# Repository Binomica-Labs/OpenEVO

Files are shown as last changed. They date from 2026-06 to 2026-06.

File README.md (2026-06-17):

# OpenEvo — Open Evolution Turbidostat

**Authors:** Zane Chan, Pin-Che Huang, Phillip Kyriakakis  
**License:** [MIT](https://opensource.org/licenses/MIT)  
**Latest Release:** [V1.1 — June 17, 2026](OpenEvo_2026-06-17_Release_V1.1.zip)

---

OpenEvo is an open-source turbidostat for continuous-culture directed evolution. It runs as a browser-based interface on any computer connected to an Arduino Mega 2560, with real-time OD monitoring, automated media changes, and optional one-click global remote access via Cloudflare Tunnel — no cloud account or router configuration needed.

---

## Download & Run

**The easiest way to get started is to download the release zip — it contains everything you need:**

➡️ [`OpenEvo_2026-06-17_Release_V1.1.zip`](OpenEvo_2026-06-17_Release_V1.1.zip) (~60 MB — includes Python interface, Arduino firmware, software interface manual, launchers, installers, and Cloudflare tunnel binaries for remote access)

**Full archive including hardware assembly manual** also available on Zenodo:  
➡️ [https://doi.org/10.5281/zenodo.20694532](https://doi.org/10.5281/zenodo.20694532)

Inside the zip you will find a `README.txt` with full installation instructions. The short version:

1. Extract the zip to a permanent location
2. Run `Windows_Install_OpenEvo.bat` or `Mac_Install_OpenEvo.command` to install Python packages
3. Upload `2026-06-04_OpenEvo_Firmware_V1.ino` to your Arduino Mega 2560 via Arduino IDE
4. Run `Windows_Run_OpenEvo.bat` or `Mac_Run_OpenEvo.command`
5. Open **http://localhost:8080** in your browser and click **Connect**

---

## What's in This Repository

| File | Description |
|---|---|
| `2026-06-17_OpenEvo_Interface_V1.1.py` | Main Python web interface (latest) |
| `2026-06-04_OpenEvo_Firmware_V1.ino` | Arduino Mega 2560 firmware |
| `OpenEVO Interface Manual.pdf` | Software interface manual |
| `Windows_Run_OpenEvo.bat` | Windows launcher |
| `Mac_Run_OpenEvo.command` | Mac launcher |
| `Windows_Install_OpenEvo.bat` | Windows package installer |
| `Mac_Install_OpenEvo.command` | Mac package installer |
| `requirements.txt` | Python dependencies |
| `OpenEvo_TEST_CHECKLIST.html` | Interactive release test checklist |
| `OpenEvo_2026-06-17_Release_V1.1.zip` | Full release zip (tracked via Git LFS) |

---

## Features

- Real-time OD monitoring with live plotting
- Automated media dilution at a configurable OD threshold
- LED cycling for directed evolution experiments
- 2–4 point OD calibration using an inverse least-squares model (`OD = a/IR + b`)
- SD card persistence — config and data survive power cycles
- Manual pump control and a cycle program editor
- CSV data export with UTC timestamps
- **One-click global remote access** via Cloudflare Tunnel (bundled, no account required)
  - Generates a public URL instantly
  - All viewers — local and remote — see the same live interface

---

## Hardware

- Arduino Mega 2560
- IR optical density sensor
- NTC thermistor temperature sensors
- Peristaltic pumps
- Stirrer motor
- LEDs
- SD card module
- USB data cable

---

## Software Requirements

- Python 3.10 or newer
- NiceGUI 3.4.1 (`pip install nicegui==3.4.1`)
- PySerial (`pip install pyserial`)
- Arduino IDE 2.x
- Windows 10/11, macOS 10.15+, or Linux

---

## Release History

| Release | Date | Notes |
|---|---|---|
| V1 | 2026-06-11 | Current release |

---

## License

MIT — see [https://opensource.org/licenses/MIT](https://opensource.org/licenses/MIT)

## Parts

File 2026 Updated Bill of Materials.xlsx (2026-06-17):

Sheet: 2025-11-24
Part Name | Quantity Needed | Retail Quantity | Unit price | Price for all | Vendor | URL
IC I2C TB6612 Mosfet Stepper Motor PCA9685 Servo Driver Shield V2 For Robot PWM Mega R3 | 1 | 1 | $9.98 | $9.98 | AliExpress | https://www.aliexpress.us/item/3256808443179819.html?curPageLogUid=ypC1EHNQtV5V
Adafruit DS3231 Real-Time Clock | 1 | 1 | $10.01 | $10.01 | AliExpress | https://www.aliexpress.us/item/3256810164925988.html?curPageLogUid=7wuj5i6TvdWM
TLC5947 module 12-Bit 24-Channel PWM LED Driver Module With Internal Oscillator 12 Bit 3-5.5V | 1 | 1 | $14.00 | $14.00 | Alibaba | https://www.alibaba.com/product-detail/TLC5947-module-12-Bit-24-Channel_62586041214.html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
Adafruit DRV8871 DC Motor Controller | 1 | 5 | $2.60 | $2.60 | AliExpress | https://www.aliexpress.us/item/3256809806051721.html?curPageLogUid=Eqp3fZFoM7K1
TSL2591 Light Sensor | 1 | 2 | $2.80 | $2.80 | Alibaba | https://www.alibaba.com/product-detail/TSL2591-Digital-Light-Sensor-Breakout-Module_1601221697469.html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
TCA9548A I2C Multiplexer Module – 1-to-8 Channel Expansion Board for IIC Bus (8-Way | 1 | 1 | $1.58 | $1.58 | AliExpress | https://www.adafruit.com/product/2717
DC Motor Peristaltic Pump | 4 | 1 | $3.66 | $14.64 | AliExpress | https://www.aliexpress.us/item/3256805882232786.html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
PTC Heating Plate 80C | 1 | 1 | $1.08 | $1.08 | AliExpress | https://www.aliexpress.us/item/2255799902168723.html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
Waterproof Button | 3 | 10 | $4.68 | $4.68 | AliExpress | https://www.aliexpress.us/item/3256803116546507.html?curPageLogUid=xL4qqrG5PEyM
5mm x 300mm Steel Rod | 2 | 2 | $1.09 | $1.09 | AliExpress | https://www.aliexpress.us/item/3256809453294379.html?curPageLogUid=2q5RW11g6f6b
Serial IIC I2C TWI 2004 204 20*4 English & Japanese Character LCD Module Display Panel Screen for Arduino | 1 | 1 | $3.52 | $3.52 | AliExpress | https://www.amazon.com/gp/product/B07TXGD3WS/ref=ppx_yo_dt_b_search_asin_title?ie=UTF8&psc=1
Matte Black PLA Filament | 1 | 1 | $17.40 | $17.40 | AliExpress | https://www.aliexpress.us/item/3256808648181661.html?curPageLogUid=riVaaNLBrUrJ
Arduino MEGA 2560 R3 | 1 | 1 | $15.58 | $15.58 | AliExpress | https://www.aliexpress.us/item/3256808853354044.html?curPageLogUid=15EhXzMV496T
12v to 5v Converter | 1 | 1 | $4.65 | $4.65 | AliExpress | https://www.aliexpress.us/item/3256806995523749.html?curPageLogUid=ehhkYzvOyuks
Pin Connector | 50 | 100 | $1.35 | $1.35 | AliExpress | https://www.aliexpress.us/item/3256806077264771.html?spm=a2
Pin Connector Housing | 100 | 100 | $1.67 | $1.67 | AliExpress | https://www.aliexpress.us/item/3256809102805756.html?curPageLogUid=IOLAuUAzc9Qd
M2.5 x 10mm Female Standoff | 20 | 20 | $3.25 | $3.25 | AliExpress | https://www.aliexpress.us/item/3256805863280885.html?curPageLogUid=uJjQn4AfzCel
M3 x 10mm Female Standoff | 20 | 20 | $2.81 | $2.81 | AliExpress | https://www.aliexpress.us/item/3256805863280885.html?curPageLogUid=uJjQn4AfzCel
Dispensing Needle 14ga 4" | 2 | 20 | $5.00 | $5.00 | AliExpress | https://www.aliexpress.us/item/3256806422675515.html
10 Pack - Dispensing Needle 10G x 5" - Blunt Tip, Luer Lock, All Metal (Stainless Steel) | 1 | 1 | $3.83 | $3.83 | AliExpress | https://www.aliexpress.us/item/2255800730053112.html?curPageLogUid=V4wyD2ZV2IoS
Dispensing Needle 14ga 1.5" | 4 | 12 | $3.74 | $3.74 | AliExpress | https://www.aliexpress.us/item/3256808088472590.html?curPageLogUid=Nd4i0lxbjFsQ
8mm x 20mm olive-shaped stir bar | 1 | 1 | $1.15 | $1.15 | AliExpress | https://www.aliexpress.us/item/2255801153708621.html?curPageLogUid=j1jyPPY7cOp3
90mL Glass Vial | 1 | 6 | $16.99 | $16.99 | AliExpress | https://www.aliexpress.us/item/3256803514646833.html?srcSns=sns_Copy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
Barrel Jack Connector 5.5x2.1mm | 1 | 1 | $2.41 | $2.41 | AliExpress | https://www.aliexpress.us/item/3256803320286941.html?curPageLogUid=eMrwFr4nFsgy
Industrial MicroSD Card 32Gb | 1 | 1 | $5.64 | $5.64 | AliExpress | https://www.aliexpress.us/item/3256807576760784.html?curPageLogUid=tyVm4Ekr2Y1j
M2.5 Hex Screw Kit 4mm, 10mm | 1 | 50 each | $3.93 | $3.93 | AliExpress | https://www.aliexpress.us/item/3256803907721123.html?curPageLogUid=memrVmdLUUmt
M3 Hex Screw Kit 4mm, 10mm, 20mm | 1 | 50 each | $7.06 | $7.06 | AliExpress | https://www.aliexpress.us/item/2251832793785357.html?curPageLogUid=0Fh3A0FxOjEa
Double Sided Tape Heavy Duty | 1 | 1 | $2.43 | $2.43 | AliExpress | https://www.aliexpress.us/item/3256804426987395.html?curPageLogUid=xIfYy00LLE2k
Rocker Switch | 1 | 5 | $1.43 | $1.43 | AliExpress | https://www.aliexpress.us/item/2251832687071918.html?curPageLogUid=4V8XkcMblquU
CR1220 Lithium Battery | 1 | 5 | $3.18 | $3.18 | AliExpress | https://www.aliexpress.us/item/3256808697007607.html?curPageLogUid=drx6CjwDRf4p
Silicone Tubing 1/8" ID x 1/4" OD | 5m | 5m | $6.02 | $6.02 | AliExpress | https://www.aliexpress.us/item/3256807463903641.html?curPageLogUid=STi7P96EXRlY
L298N Motor Controller | 1 | 1 | $2.04 | $2.04 | AliExpress | https://www.aliexpress.us/item/3256805515428257.html?curPageLogUid=RA7wxDvjNB5x
Female Pin Header Kit | 1 | 10 | $6.36 | $6.36 | AliExpress | https://www.aliexpress.us/item/3256803424019097.html?curPageLogUid=tNNR6Pz63qkk
Male Pin Header Strips | 2 | 10 | $3.93 | $3.93 | AliExpress | https://www.aliexpress.us/item/3256809164675006.html?curPageLogUid=NwdbH9P0lvf9
Male Pin Header Right Angle Strips | 1 | 10 | $1.54 | $1.54 | AliExpress | https://www.aliexpress.us/item/3256807383526945.html?curPageLogUid=kdMGiPZ6hEm8
2.54mm Jumper Caps | 4 | 100 | $1.26 | $1.26 | AliExpress | https://www.aliexpress.us/item/3256805359306528.html?curPageLogUid=xutyn0z4C155
12v 5A Power Supply | 1 | 1 | $8.05 | $8.05 | AliExpress | https://www.aliexpress.us/item/3256805577151044.html?curPageLogUid=hN4PaRkEcDTU
Square Adhesive Rubber Feet | 1 | 40 | $2.92 | $2.92 | AliExpress | https://www.aliexpress.us/item/2251832785210189.html?curPageLogUid=zY0jLTF8NWrz
PES 0.22um Syringe Filters | 5 | 10 | $11.15 | $11.15 | AliExpress | https://www.aliexpress.us/item/3256806983863516.html?curPageLogUid=6LAvoEP7xlQJ
Neodymium Magnets 12x6x3mm | 16 | 20 | $4.20 | $4.20 | AliExpress | https://www.aliexpress.us/item/3256809286779220.html?curPageLogUid=kWDl0wbewySA
PC Fan 40x20mm | 1 | 1 | $2.86 | $2.86 | AliExpress | https://www.aliexpress.us/item/3256802954170154.html?curPageLogUid=QPYlJY3zycg1
MicroSD Card Module | 1 | 1 | $1.00 | $1.00 | AliExpress | https://www.aliexpress.us/item/3256806271288304.html?curPageLogUid=6h4WNfpqXEIP
Black High Temp Silicone Sealant | 1 | 1 | $3.44 | $3.44 | AliExpress | https://www.aliexpress.us/item/3256809082794580.html?curPageLogUid=5iZxJbS0rAOQ
22AWG Silicone Wire Kit Box 1 | 1 | 1 | $17.16 | $17.16 | AliExpress | https://www.aliexpress.us/item/3256806872487663.html?curPageLogUid=m3JkRzS8uJco
22AWG Silicone Wire Kit Box 2 | 1 | 1 | $16.86 | $16.86 | AliExpress | https://www.aliexpress.us/item/3256806872487663.html?curPageLogUid=m3JkRzS8uJco
Smooth Flow Flux | 1 | 1 | $5.54 | $5.54 | AliExpress | https://www.aliexpress.us/item/3256807619367300.html?curPageLogUid=2C5Q7TgWCZ7L
Lead-Free Solder | 1 | 1 | $4.59 | $4.59 | AliExpress | https://www.aliexpress.us/item/3256807913795917.html?curPageLogUid=2KA0dfwCmOtA
Hard Silicone Rubber Casting Resin | 1 | 1 | $20.59 | $20.59 | Amazon | https://www.amazon.com/dp/B07YWBXVND?ref_=ppx_hzsearch_conn_dt_b_fed_asin_title_2&th=1
Luer Lock Female to Barb 1/8" Cat# 51525K293 | 16 | 30 | $6.99 | $4.59 | Amazon | https://www.amazon.com/Syringe-Adapter-Female-Connector-Coupler/dp/B0BMFJSJP1
Luer Lock Male to Barb 1/8" Cat# 51525K143 | 16 | 30 | $7.49 | $7.49 | Amazon | https://www.amazon.com/AIEX-Syringe-Coupler-Adapter-Connector/dp/B0B8CJVX3S
Precision 10K Ohm Resistor | 1 | 1 | $1.99 | $1.99 | Mouser | https://www.amazon.com/PTF5610K000BZBF-Resistors-Through-10Kohms-PTF-56/dp/B09G76FF29
Precision 10K Ohm NTC Thermistor | 1 | 1 | $3.11 | $3.11 | DigiKey | https://www.digikey.com/en/products/detail/epcos-tdk-electronics/B57550G1103F005/3500387?gad_source=1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
Precision 2.49K Ohm Resistor | 1 | 1 | $0.59 | $0.59 | Mouser | https://www.digikey.com/en/products/detail/stackpole-electronics-inc/RNF14BTE2K49/1752591
 |  |  | TOTAL | $306.76
Equipment
Helping Hands | 1 | 1 | $19.99 | $19.99 | Amazon | https://www.amazon.com/dp/B0FGTBKRN6?sp_csd=d2lkZ2V0TmFtZT1zcF9kZXRhaWxfdGhlbWF0aWM
Soldering Iron, 160W High Power Soldering Tool, LED Digital Display Temperature Control Accurate 392°F-932°F, with ON/OFF Switch, 3 Iron Tips, Stand,Flux, Automatic Sleep Mode | 1 | 1 | $14.29 | $14.29 | Amazon | https://www.amazon.com/dp/B0CRKSM2GH?s=hi&sp_csd=d2lkZ2V0TmFtZT1zcF9kZXRhaWxfdGhlbWF0aWM
Optional LEDs (100 UV-NIR, includes shipping) |  |  | $70.00 | $70.00 | Alibaba | https://www.alibaba.com/product-detail/5mm3mm-ultraviolet-led-high-power-epistar_1600714829021.html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
Optional Black Mica powder | 1 | 1 | $0.95 | $0.95 | AliExpress | https://www.aliexpress.us/item/3256805821013496.html?src=google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
Optional pump for air blubbling | 1 | 1 | $14.99 | $14.99 | Amazon | http://amazon.com/Uniclife-Aquarium-Outlets-Accessories-Adjustable/dp/B01EBXI7PG/

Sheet: Second bot parts
Part Name | Quantity Needed | Retail Quantity | Unit price | Price for all | Vendor | URL
IC I2C TB6612 Mosfet Stepper Motor PCA9685 Servo Driver Shield V2 For Robot PWM Mega R3 | 1 | 1 | $9.98 | $9.98 | AliExpress | https://www.aliexpress.us/item/3256808443179819.html?curPageLogUid=ypC1EHNQtV5V
Adafruit DS3231 Real-Time Clock | 1 | 1 | $10.01 | $10.01 | AliExpress | https://www.aliexpress.us/item/3256810164925988.html?curPageLogUid=7wuj5i6TvdWM
TLC5947 module 12-Bit 24-Channel PWM LED Driver Module With Internal Oscillator 12 Bit 3-5.5V | 1 | 1 | $14.00 | $14.00 | Alibaba | https://www.alibaba.com/product-detail/TLC5947-module-12-Bit-24-Channel_62586041214.html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
TCA9548A I2C Multiplexer Module – 1-to-8 Channel Expansion Board for IIC Bus (8-Way | 1 | 1 | $1.58 | $1.58 | AliExpress | https://www.adafruit.com/product/2717
DC Motor Peristaltic Pump | 4 | 1 | $3.66 | $14.64 | AliExpress | https://www.aliexpress.us/item/3256805882232786.html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
PTC Heating Plate 80C | 1 | 1 | $1.08 | $1.08 | AliExpress | https://www.aliexpress.us/item/2255799902168723.html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
5mm x 300mm Steel Rod | 2 | 2 | $1.09 | $1.09 | AliExpress | https://www.aliexpress.us/item/3256809453294379.html?curPageLogUid=2q5RW11g6f6b
Serial IIC I2C TWI 2004 204 20*4 English & Japanese Character LCD Module Display Panel Screen for Arduino | 1 | 1 | $3.52 | $3.52 | AliExpress | https://www.amazon.com/gp/product/B07TXGD3WS/ref=ppx_yo_dt_b_search_asin_title?ie=UTF8&psc=1
Matte Black PLA Filament | 1 | 1 | $17.40 | $17.40 | AliExpress | https://www.aliexpress.us/item/3256808648181661.html?curPageLogUid=riVaaNLBrUrJ
Arduino MEGA 2560 R3 | 1 | 1 | $15.58 | $15.58 | AliExpress | https://www.aliexpress.us/item/3256808853354044.html?curPageLogUid=15EhXzMV496T
12v to 5v Converter | 1 | 1 | $4.65 | $4.65 | AliExpress | https://www.aliexpress.us/item/3256806995523749.html?curPageLogUid=ehhkYzvOyuks
Pin Connector | 50 | 100 | $1.35 | $1.35 | AliExpress | https://www.aliexpress.us/item/3256806077264771.html?spm=a2
Pin Connector Housing | 100 | 100 | $1.67 | $1.67 | AliExpress | https://www.aliexpress.us/item/3256809102805756.html?curPageLogUid=IOLAuUAzc9Qd
M2.5 x 10mm Female Standoff | 20 | 20 | $3.25 | $3.25 | AliExpress | https://www.aliexpress.us/item/3256805863280885.html?curPageLogUid=uJjQn4AfzCel
M3 x 10mm Female Standoff | 20 | 20 | $2.81 | $2.81 | AliExpress | https://www.aliexpress.us/item/3256805863280885.html?curPageLogUid=uJjQn4AfzCel
10 Pack - Dispensing Needle 10G x 5" - Blunt Tip, Luer Lock, All Metal (Stainless Steel) | 1 | 1 | $3.83 | $3.83 | AliExpress | https://www.aliexpress.us/item/2255800730053112.html?curPageLogUid=V4wyD2ZV2IoS
8mm x 20mm olive-shaped stir bar | 1 | 1 | $1.15 | $1.15 | AliExpress | https://www.aliexpress.us/item/2255801153708621.html?curPageLogUid=j1jyPPY7cOp3
90mL Glass Vial | 1 | 6 | $16.99 | $16.99 | AliExpress | https://www.aliexpress.us/item/3256803514646833.html?srcSns=sns_Copy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
Barrel Jack Connector 5.5x2.1mm | 1 | 1 | $2.41 | $2.41 | AliExpress | https://www.aliexpress.us/item/3256803320286941.html?curPageLogUid=eMrwFr4nFsgy
Industrial MicroSD Card 32Gb | 1 | 1 | $5.64 | $5.64 | AliExpress | https://www.aliexpress.us/item/3256807576760784.html?curPageLogUid=tyVm4Ekr2Y1j
Double Sided Tape Heavy Duty | 1 | 1 | $2.43 | $2.43 | AliExpress | https://www.aliexpress.us/item/3256804426987395.html?curPageLogUid=xIfYy00LLE2k
L298N Motor Controller | 1 | 1 | $2.04 | $2.04 | AliExpress | https://www.aliexpress.us/item/3256805515428257.html?curPageLogUid=RA7wxDvjNB5x
Female Pin Header Kit | 1 | 10 | $6.36 | $6.36 | AliExpress | https://www.aliexpress.us/item/3256803424019097.html?curPageLogUid=tNNR6Pz63qkk
12v 5A Power Supply | 1 | 1 | $8.05 | $8.05 | AliExpress | https://www.aliexpress.us/item/3256805577151044.html?curPageLogUid=hN4PaRkEcDTU
Hard Silicone Rubber Casting Resin | 1 | 1 | $18.99 | $18.99 | Amazon | https://www.amazon.com/dp/B07YWBXVND?ref_=ppx_hzsearch_conn_dt_b_fed_asin_title_2&th=1
Neodymium Magnets 12x6x3mm | 16 | 20 | $4.20 | $4.20 | AliExpress | https://www.aliexpress.us/item/3256809286779220.html?curPageLogUid=kWDl0wbewySA
PC Fan 40x20mm | 1 | 1 | $2.86 | $2.86 | AliExpress | https://www.aliexpress.us/item/3256802954170154.html?curPageLogUid=QPYlJY3zycg1
MicroSD Card Module | 1 | 1 | $1.00 | $1.00 | AliExpress | https://www.aliexpress.us/item/3256806271288304.html?curPageLogUid=6h4WNfpqXEIP
Luer Lock Female to Barb 1/8" Cat# 51525K293 | 16 | 30 | $6.99 | $6.99 | Amazon | https://www.amazon.com/Syringe-Adapter-Female-Connector-Coupler/dp/B0BMFJSJP1
Luer Lock Male to Barb 1/8" Cat# 51525K143 | 16 | 30 | $7.49 | $7.49 | Amazon | https://www.amazon.com/AIEX-Syringe-Coupler-Adapter-Connector/dp/B0B8CJVX3S
Precision 10K Ohm Resistor | 1 | 1 | $1.99 | $1.99 | Mouser | https://www.amazon.com/PTF5610K000BZBF-Resistors-Through-10Kohms-PTF-56/dp/B09G76FF29
Precision 10K Ohm NTC Thermistor | 1 | 1 | $3.11 | $3.11 | DigiKey | https://www.digikey.com/en/products/detail/epcos-tdk-electronics/B57550G1103F005/3500387?gad_source=1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
Precision 2.49K Ohm Resistor | 1 | 1 | $0.59 | $0.59 | Mouser | https://www.digikey.com/en/products/detail/stackpole-electronics-inc/RNF14BTE2K49/1752591
 |  |  | TOTAL | $198.73

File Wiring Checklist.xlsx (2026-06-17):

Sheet: Wire list
Black (17 wires) | Green (6 wires) | White (6 wires)
2× 5 cm | 1× 5 cm | 1× 7 cm
1× 6 cm | 1× 8 cm | 1× 8 cm
1× 8 cm | 1× 12 cm | 1× 14 cm
1× 10 cm | 1× 33 cm | 3× 38 cm
2× 11 cm | 2× 38 cm
1× 12 cm | Yellow (4 wires) | Purple (2 wires)
3× 20 cm | 1× 5 cm | 1× 14 cm
1× 25 cm | 1× 12 cm | 1× 38 cm
1× 28 cm | 1× 33 cm | Rainbow (1 wire)
2× 30 cm | 1× 38 cm | 1× 33 cm
2× 38 cm | Blue (4 wires) | Naked/bare (1 wire)
Orange (14 wires) | 1× 7 cm | 1× 5 cm
3× 5 cm | 1× 8 cm
1× 11 cm | 1× 14 cm
1× 12 cm | 1× 38 cm
1× 14 cm | Pink (3 wires)
2× 20 cm | 1× 14 cm
5× 28 cm | 2× 38 cm
1× 38 cm | Brown (3 wires)
Red (10 wires) | 1× 14 cm
1× 5 cm | 1× 26 cm
1× 6 cm | 1× 38 cm
1× 10 cm
1× 11 cm
2× 20 cm
1× 25 cm
2× 30 cm
1× 38 cm
Total: 71 wires, ~14.7 m of wire. The two biggest batch cuts are the 38 cm group (16 wires across many colors) and the 5 cm group (9 wires) — worth cutting those in batches first

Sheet: Wire descriptions
Part Pin | Connect to Pin | Wire Color | Wire Length (cm) | Connection Type
Button DOWN | Arduino 22 | Green | 38 | Solder-Male
Button Group GND | GND Rail | Black | 38 | Solder-Male
Button SELECT | Arduino 24 | White | 38 | Solder-Male
Button UP | Arduino 26 | Blue | 38 | Solder-Male
Heater Controller ENA | Arduino 44 | Pink | 14 | Female-Male
Heater Controller ENB | Arduino 34 | Blue | 14 | Female-Male
Heater Controller IN1 | Arduino 42 | Brown | 14 | Female-Male
Heater Controller IN2 | Arduino 40 | Purple | 14 | Female-Male
Heater Controller IN3 | Arduino 38 | Orange | 14 | Female-Male
Heater Controller IN4 | Arduino 36 | White | 14 | Female-Male
Heater Controller 12v | 12v Rail | Orange | 11 | Solder-Male
Heater Controller GND | GND Rail | Black | 11 | Solder-Male
I2C Multiplexer GND | GND Rail | Black | 5 | Female-Male
I2C Multiplexer SCL | Arduino SCL1 / port 21 | Green | 12 | Female-Male
I2C Multiplexer SDA | Arduino SDA1 / port 20 | Yellow | 12 | Female-Male
I2C Multiplexer Vcc | 5v Rail | Red | 5 | Female-Male
LCD Screen GND | GND Rail | Black | 30 | Female-Male
LCD Screen SCL | I2C Multiplexer SCL0 | Green | 38 | Female-Female
LCD Screen SDA | I2C Multiplexer SDA0 | Yellow | 38 | Female-Female
LCD Screen Vcc | 5v Rail | Red | 30 | Female-Male
LED PWM Controller Clock | Arduino 27 | Blue | 8 | Male-Male
LED PWM Controller Data | Arduino 25 | White | 8 | Male-Male
LED PWM Controller GND | GND Rail | Black | 6 | Male-Male
LED PWM Controller Latch | Arduino 23 | Green | 8 | Male-Male
LED PWM Controller Vcc | 5v Rail | Red | 6 | Male-Male
OD940 Light | LED Controller 0 | White | 38 | Solder-Female
OD940 Light | LED Controller 0 | White | 38 | Solder-Female
OD940 Sensor SDA | I2C Multiplexer SDA2 | Yellow | 33 | Female-Female
Opto LED SixPack | LED Controller 1-7 | Rainbow | 33 | Solder-Female
Real-Time Clock GND | GND Rail | Black | 11 | Female-Male
Real-Time Clock SCL | I2C Multiplexer SCL1 | Green | 5 | Female-Female
Real-Time Clock SDA | I2C Multiplexer SDA1 | Yellow | 5 | Female-Female
Real-Time Clock Vcc | 5v Rail | Red | 11 | Female-Male
SD Card Module CS | Arduino 53 | Brown | 38 | Female-Male
SD Card Module GND | GND Rail | Black | 30 | Female-Male
SD Card Module MISO | Arduino 50 | Purple | 38 | Female-Male
SD Card Module MOSI | Arduino 51 | Orange | 38 | Female-Male
SD Card Module SCK | Arduino 52 | Pink | 38 | Female-Male
SD Card Module Vcc | 5v Rail | Red | 30 | Female-Male
Stirring Controller IN1 | Arduino 48 | Blue | 7 | Female-Male
Stirring Controller IN2 | Arduino 46 | White | 7 | Female-Male
Thermistor Heater | Arduino A9 | Brown | 26 | Female-Male
Thermistor Media | Arduino A8 | Pink | 38 | Female-Male
Heater Pad Top Left | Heater Controller OUT1 | Orange | 28 | Solder-Solder
Heater Pad Top Right | Heater Controller OUT2 | Orange | 28 | Solder-Solder
Heater Pad Bottom Left | Heater Controller OUT3 | Orange | 28 | Solder-Solder
Heater Pad Bottom Left | Heater Controller OUT4 | Orange | 28 | Solder-Solder
Stirring Fan 12v | Stirrer Controller OUT2 | Orange | 28 | Solder-Solder
Stirring Fan GND | Stirrer Controller OUT1 | Black | 28 | Solder-Solder
CNC Shield 12v + | 12v Rail | Orange | 12 | Solder-Male
CNC Shield 12v - (GND) | GND Rail | Black | 12 | Solder-Male
Stirrer Motor Controller Power + | 12v Rail | Orange | 5 | Solder-Male
Stirrer Motor Controller Power - (GND) | GND Rail | Black | 5 | Solder-Male
button | button | naked | 5 | Solder-Solder
pump motor | CNC shield M1, M2, M3, M4 | orange | 20 | Solder-Solder
12V converter negative input ground | barrel jack connector ground lead | black | 8 | Solder-Solder
12V converter positive input power | rocker switch | orange | 5 | Solder-Solder
rocker switch | 20-pin female header | orange | 20 | Solder-Solder
12V converter negative output power | 20-pin female header | red | 20 | Solder-Solder
12V converter negative output ground | 20-pin female header | black | 20 | Solder-Solder
barrel jack connector ground lead | 20-pin female header | black | 20 | Solder-Solder
rocker switch | barrel jack connector ground lead | orange | 5 | Solder-Solder
Arduino 5v | 5v Rail | red | 10 | Male-Male
Arduino GND | GND Rail | black | 10 | Male-Male
thermistor heater | 5v Rail | red | 20 | Female-Male
thermistor heater | GND Rail | black | 20 | Female-Male
thermistor media | 5v Rail | red | 38 | Female-Male
thermistor media | GND Rail | black | 38 | Female-Male
sensor board SCL | I2C Multiplexer SCL2 | green | 33 | Female-Female
sensor board VIN | 5v Rail | red | 25 | Female-Male
sensor board GND | GND Rail | black | 25 | Female-Male

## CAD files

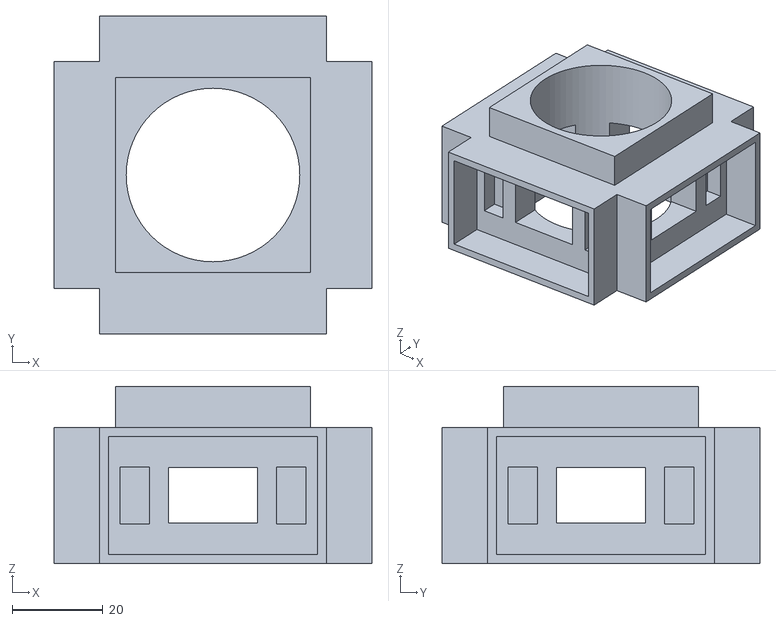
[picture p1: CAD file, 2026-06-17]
STL Files/Module L - OEVO Module Bay.stl
70.0 x 70.0 x 39.0

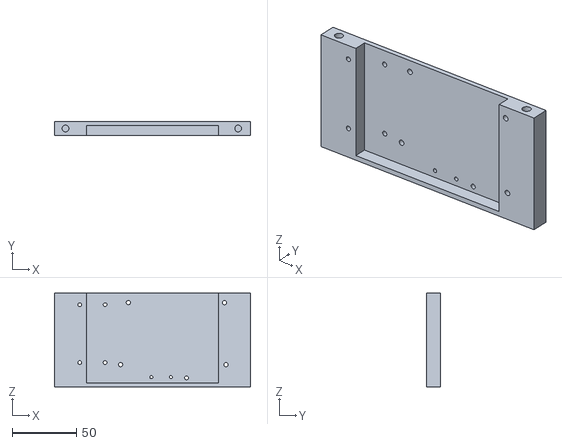
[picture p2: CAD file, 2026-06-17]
STL Files/Module F - OEVO Mother Board Rail.stl
153.0 x 11.0 x 73.0

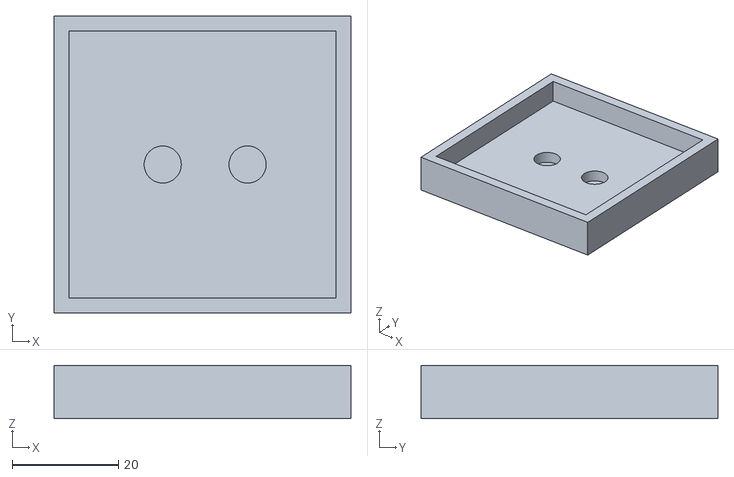
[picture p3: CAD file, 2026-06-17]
STL Files/Module T - OEVO Bottle Top Part 1.stl
56.0 x 56.0 x 10.0

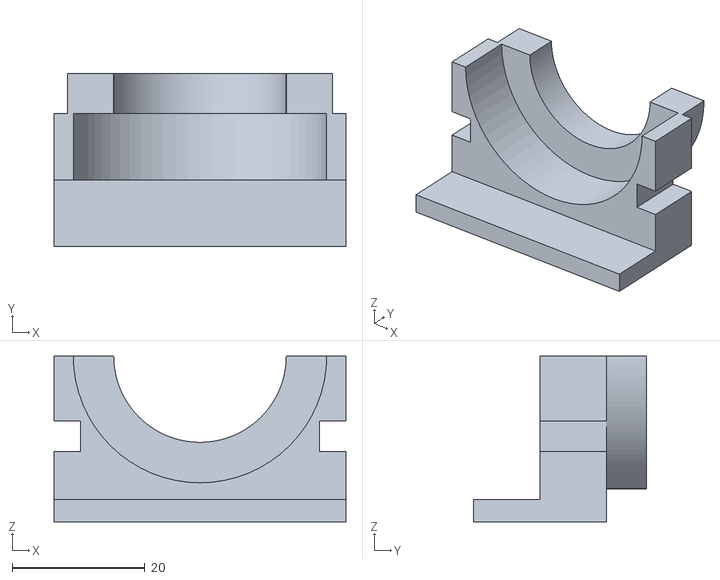
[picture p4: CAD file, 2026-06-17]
STL Files/Module S - OEVO Top light blocker.stl
44.0 x 26.0 x 25.0

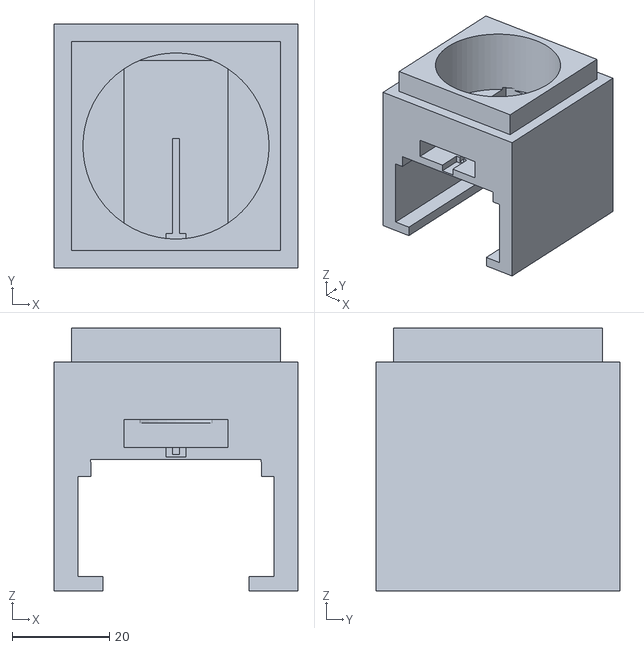
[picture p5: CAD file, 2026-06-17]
STL Files/Module D - OEVO Heater-Stirrer base.stl
50.0 x 50.0 x 54.0

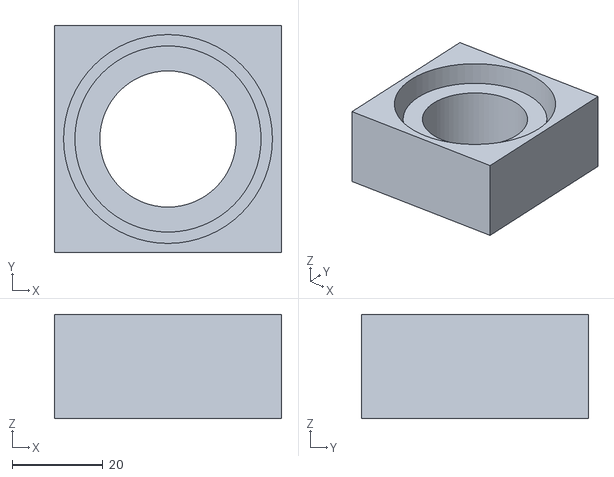
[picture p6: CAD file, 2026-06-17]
STL Files/Module U - OEVO Media Bottle Top Part 2.stl
50.0 x 50.0 x 23.0

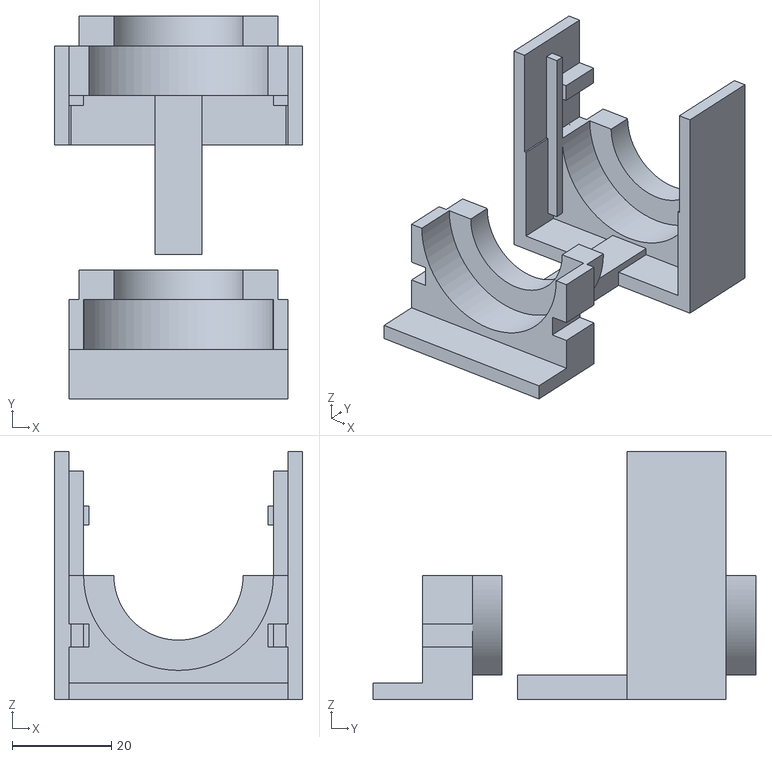
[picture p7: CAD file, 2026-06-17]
STL Files/Module R - OEVO top light blocker.stl
50.0 x 77.1 x 50.0

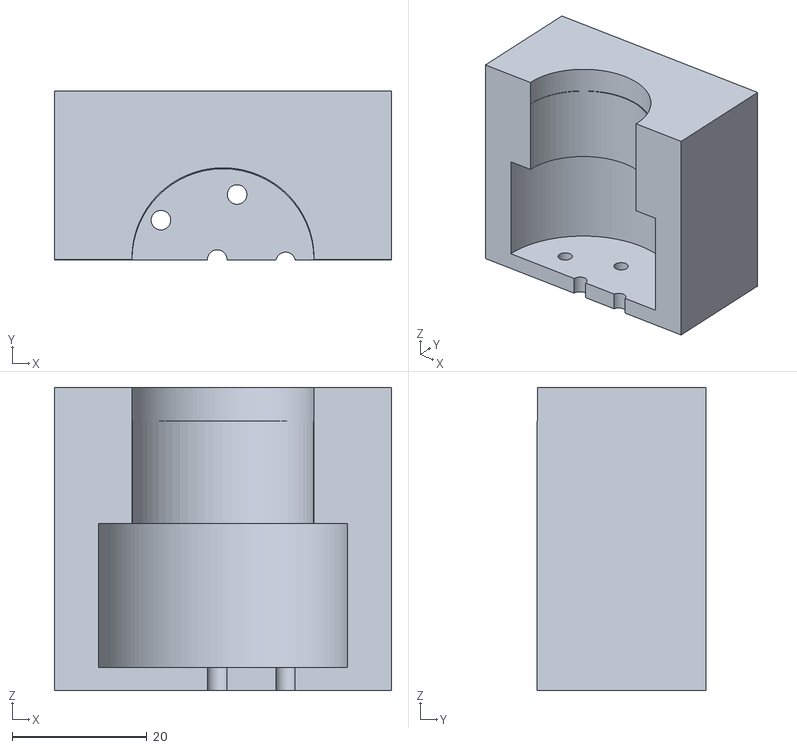
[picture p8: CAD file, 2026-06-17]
STL Files/Module J - OEVO Reactor Cap Mold Right.stl
50.0 x 25.0 x 45.0

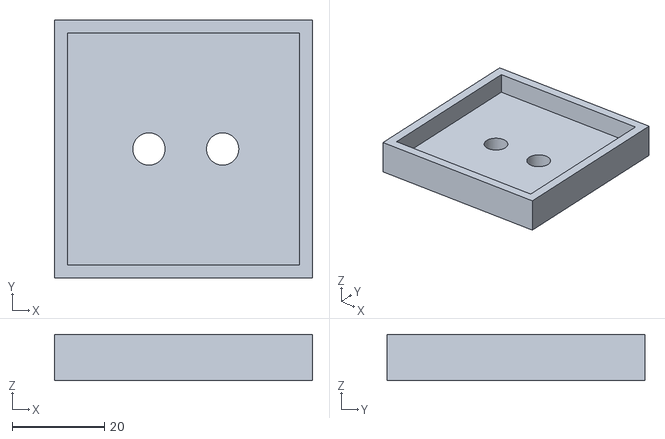
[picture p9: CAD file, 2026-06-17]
STL Files/Module V - OEVO Media Bottle Top Part 3.stl
56.0 x 56.0 x 10.00

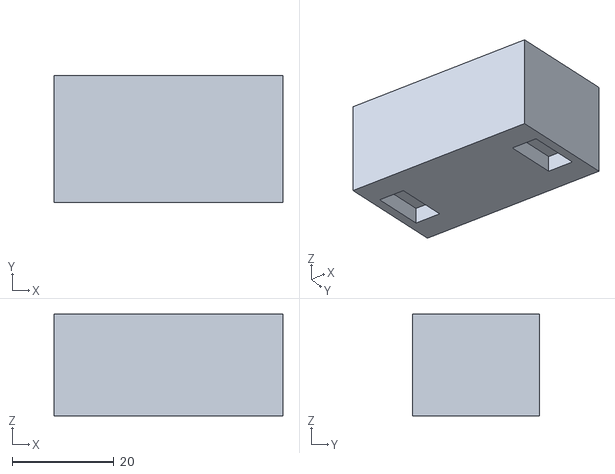
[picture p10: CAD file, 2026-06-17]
STL Files/Module M - OEVO Blank Module.stl
45.0 x 25.0 x 20.0

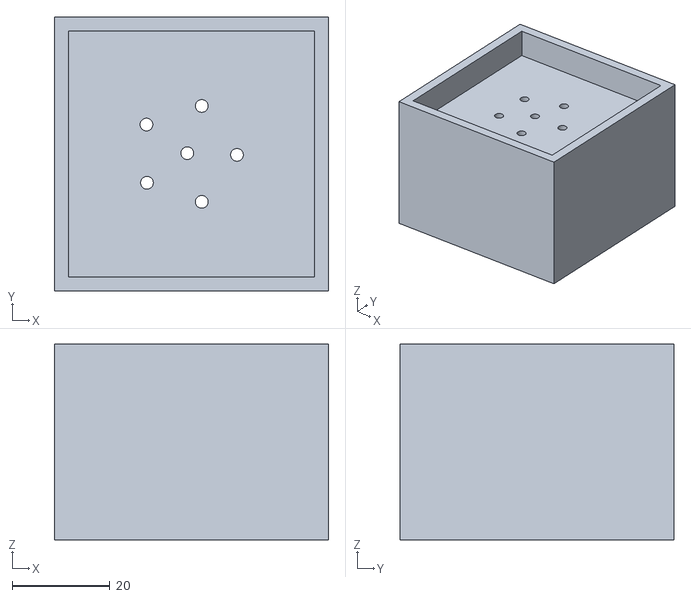
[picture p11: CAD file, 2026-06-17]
STL Files/Module H - OEVO Reactor Cap mold Bottom.stl
56.0 x 56.0 x 40.0

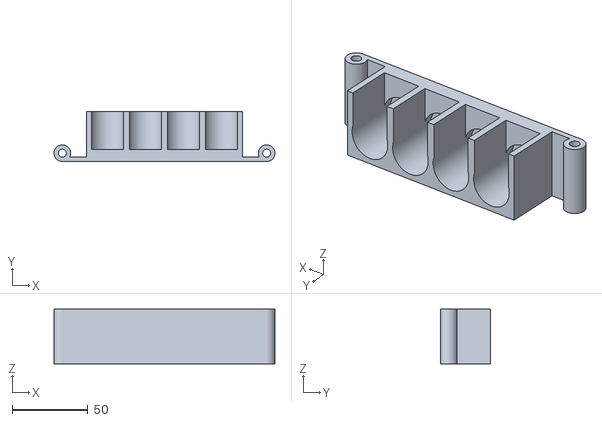
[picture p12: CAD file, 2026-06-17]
STL Files/Module G - OEVO DC Motor Rail.stl
145.8 x 33.0 x 36.0

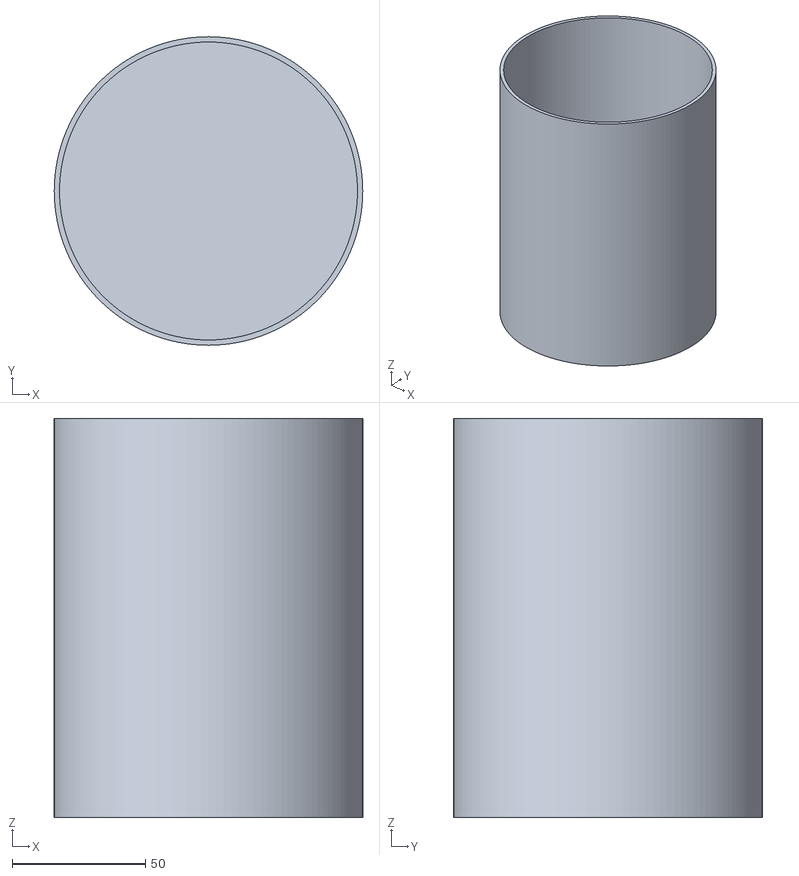
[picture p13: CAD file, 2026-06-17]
STL Files/Module X - OEVO Media Light Blocker Part 1.stl
116.0 x 116.0 x 150.0

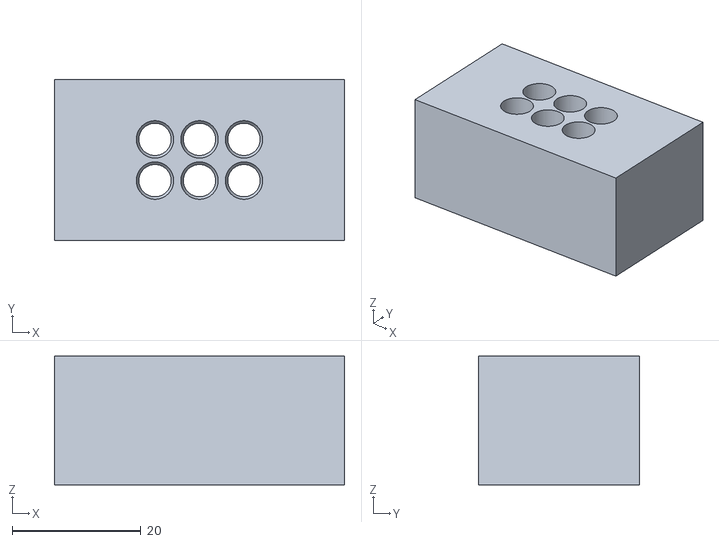
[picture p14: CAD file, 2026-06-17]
STL Files/Module P - OEVO LED SixPack Module.stl
45.0 x 25.0 x 20.0

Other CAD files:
STL Files/Module K - OEVO Reactor Cap Mold Top.stl
STL Files/Module Z - OEVO Media Light Blocker Part 3.stl
STL Files/Module C - OEVO Stirrer Rail.stl
STL Files/Module A - OEVO LCD Rail.stl
STL Files/Module B - OEVO LCD Faceplate.stl
STL Files/Module E - OEVO Mother Board.stl
STL Files/Module I - OEVO Reactor Cap Mold Left.stl
STL Files/Module O - OEVO OD Light Module.stl
STL Files/Module Q - OEVO Reactor Top.stl
STL Files/Module W - OEVO Media Bottle Top Part 4.stl
STL Files/Module Y - OEVO Media Light Blocker Part 2.stl

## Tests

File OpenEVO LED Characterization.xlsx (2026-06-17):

Wavelength | #1 365-370 | #2 380-385 | #3 400-405 | #4 420-415 | #5 420-425 | #6 430-435 | #7 455-460 | #8 465-470 | #9 480-485 | #10 500-505 | #11 520-525 | #12 530-535 | #13 590-595 | #14 600-605 | #15 630-635 | #16 660-665 | #17 680-685 | #18 700-705 | #19 720-725 | #20 760-765 | #21 780-785 | #22 800-805 | #23 820-825 | #24 850-855 | #25 880-885 | #26 900-905 | #27 940-945
198.0 | 0.0151 | 0.0021 | 0.0027 | 0.0036 | 0.0046 | 0.0028 | 0.0014 | 0.0019 | 0.0043 | 0.0030 | 0.0027 | -0.0001 | 0.0009 | 0.0030 | 0.0009 | 0.0050 | 0.0027 | 0.0049 | 0.0048 | 0.0021 | -0.0005 | 0.0046 | 0.0022 | 0.0040 | 0.0029 | 0.0071 | 0.0095
198.2 | -0.0123 | -0.0027 | -0.0027 | -0.0029 | -0.0019 | -0.0007 | -0.0010 | -0.0008 | -0.0021 | -0.0032 | -0.0011 | -0.0038 | -0.0018 | -0.0003 | 0.0011 | 0.0003 | -0.0005 | -0.0047 | -0.0030 | -0.0032 | -0.0015 | -0.0027 | -0.0046 | -0.0039 | -0.0036 | -0.0027 | -0.0077
198.4 | -0.0151 | -0.0006 | -0.0036 | 0.0013 | -0.0044 | -0.0019 | 0.0010 | -0.0005 | -0.0050 | -0.0013 | -0.0012 | -0.0024 | 0.0003 | 0.0014 | 0.0012 | -0.0003 | 0.0021 | -0.0009 | -0.0024 | 0.0003 | 0.0007 | -0.0024 | -0.0012 | -0.0013 | -0.0030 | -0.0044 | -0.0061
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

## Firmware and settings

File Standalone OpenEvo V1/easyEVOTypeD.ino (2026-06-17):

// *******************************************************************************************************************************************
// easyEVO Type D Directed Evolution Engine
// Version: 1.5.0.0
// Copyright 2024 Binomica Labs
// Author: Sebastian S. Cocioba
// License: MIT License (https://opensource.org/licenses/MIT)
//
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
// The above copyright notice and this permission notice shall be included in all copies or substantial portions of the Software.
//
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
// *******************************************************************************************************************************************



// ---------------------------------------***-PINS-***----------------------------------------------------------------------------------------
//
//
//
//  Heater Controller
//      ENA   44
//      IN1   42
//      IN2   40
//      IN3   38
//      IN4   36
//      ENB   34
//
//  Stirring Controller
//      IN1   48
//      IN2   46
//
//  Heater Thermistor
//            A9
//
//  Media Thermistor
//            A8
//
//  SD Card Reader Module:
//      MOSI  51
//      MISO  50
//      SCK   52
//      CS    53
//
//  Adafruit 24-Channel LED Driver
//      940-945nm LED 0   //OD940 sensor light
//      660-665nm LED 1   
//      720-725nm LED 2   
//      760-765nm LED 3   
//      780-785nm LED 4   
//      800-805nm LED 5   
//      820-825nm LED 6
//
//  Interface Buttons:
//      UP   26
//      SEL  24
//      DWN  22
//
//  I2C Bus Rail
//      SDA   20
//      SCL   21
//
//  I2C Multiplexer Connections
//      LCD Screen        SDA0/SCL0   setMultiplexerFocus(0) //function call to listen to specific I2C pin on multiplexer, call before use
//      Real-Time Clock   SDA1/SCL1   setMultiplexerFocus(1)
//      TSL2591 Sensor    SDA2/SCL2   setMultiplexerFocus(2)
// -------------------------------------------------------------------------------------------------------------------------------------------



// LIBRARY STUFF
#include <PID_v1.h> //PID by Brett Beauregard
#include <math.h>
#include <RTClib.h> //RTClib by Adafruit
#include <SPI.h>    // SPI library for SD card module
#include <SD.h>     // SD card library
#include <Wire.h>
#include <LiquidCrystal_I2C.h> //LiquidCrystalI2C by Frank de Brabander
#include <Adafruit_Sensor.h>  //Adafruit Unified Sensor Library
#include "Adafruit_TSL2591.h" //install all dependencies including Adafruit Unified Sensor Library
#include <StateMachine.h> //StateMachine by Jose Jullan + LinkedList dependency
#include "Arduino.h"
#include "avdweb_Switch.h" //Switch by Albert van Dalen
#include "Adafruit_TLC5947.h" //Adafruit TLC5947 by Adafruit
#include <NTC_Thermistor.h> //***INSTALL VERSION 2.0.3 ONLY; library has a bug!!!*** NTC_Thermistor by Yurii Salimov
#include <SmoothThermistor.h> //SmoothThermistor by Gianni Van Hoecke
#include <Adafruit_MotorShield.h> //Adafruit Motor Shield V2 Library + ALL Dependencies



// CRITICAL SETTINGS
const String softwareVersion = "v1.6.0.0";
const String csvFileHeader =   "unixTime,"
                          "upTime,"
                          "currentProgramTime,"
                          "ambientTemp,mediaTemp,"
                          "heaterPlateTemp,"
                          "heaterPWM,"
                          "growthDuration,"
                          "growthDurationChange,"
                          "neutralCycleCount,"
                          "positiveCycleCount,"
                          "negativeCycleCount,"
                          "totalCycleCount,"
                          "fullSpectrumReading,"
                          "visibleSpectrumReading,"
                          "infraredReading,"
                          "OD940\n";

//the temperature you wish your culture vessel to hold in degrees Celsius.
float incubationSetpointTemp = 30.00;

//keep constant to ensure consistent stirring speed
int motorStirringSpeed = 60;

//initial brightness of the 940nm Optical Density LED; adjust to reduce saturation
int OD940LEDBrightness = 2100;

//motor turning speed, calibrate your motors to determine these values below
int pumpOneSpeed = 1080;

int pumpTwoSpeed = 1140;

int pumpThreeSpeed = 1140;

int pumpFourSpeed = 1110;



//how many media refresh cycles for neutral media in Light Cycler mode
int neutralCycleMax = 1;

//how many media refresh cycles for positive selection media in Light Cycler mode
int positiveCycleMax = 1;

//how many media refresh cycles for negative selection media in Light Cycler mode
int negativeCycleMax = 1;

//how many media refresh cycles for the second neutral selection media (same bottle; for cell recovery) in Light Cycler mode
int neutralCycleTwoMax = 1;

//1Hz master loop interval in milliseconds
const int interval = 1000;

//0.1Hz turbidostat loop interval (adjusted for time spent dispensing)
const int intervalTurbidostat = 1000;

//0.1Hz LightCycler loop interval (adjusted for time spent dispensing)
const int intervalLightcycler = 1000;



// STATE STUFF
bool flagGoToStandby = false;
bool flagGoToMenu = false;
bool flagGoToTurbidostat = false;
bool flagGoToIncubate = false;
bool flagGoToHeaterTest = false;
bool flagGoToPrimePumps = false;
bool flagGoToCalibrateStirring = false;
bool flagGoToCalibrateOptics = false;
bool flagGoToCalibratePumpOne = false;
bool flagGoToCalibratePumpTwo = false;
bool flagGoToCalibratePumpThree = false;
bool flagGoToCalibratePumpFour = false;
bool displayStatPage = false;



// CRITICAL VARIABLES
unsigned long currentUnixTime = 0;
float currentOD940 = 0.0000;
unsigned long robotStartTime = 0;
unsigned long programStartTime = 0;
unsigned long currentProgramTime = 0;
unsigned long upTime = 0;
double mediaTemp = 0.00;                        //temp inside culture vessel; the media itself
double heaterPlateTemp = 0.00;                  //temp on surface of heater plate
double ambientTemp = 0.00;                      //ambient room temp as measured by the real-time clock module



int growthStartTime = 0;
int growthStopTime = 0;
int growthDuration = 0;
int growthDurationChange = 0;
int previousGrowthDuration = 0;

int cycleDuration = 0;

int totalCycleCount = 0;

int neutralCycleCount = 0;
int positiveCycleCount = 0;
int negativeCycleCount = 0;

String mediaCycleArray[20][9];    //limit the total size to less than 50 entries or memory will be full. Rely on patterns.
int currentMediaDispenseCount = 0;
int currentMediaPumpNumber = 1;
int wastePumpNumber = 4;

int currentStepNumber = 0;
String currentMediaType = "";
double currentMediaTempSetpoint = 0.00;
int currentStimulationLEDNumber = 0;
int currentStimulationLEDIntensity = 0;
float currentOpticalDensityFloor = 0.000;
float currentOpticalDensityCeiling = 2.000; //
int currentStirringSpeed = 0;
int currentCycleTimeoutDuration = 0;
int currentCycleStep = 1;
int totalProgramCycles = 0;


//  PERISTALTIC PUMP CONTROLLER STUFF (DC Motor Shield)
int pumpSelection = 1;                                //an incremented variable to easily select which pump in a for-loop during priming (1 to 4)
Adafruit_MotorShield MotorShield = Adafruit_MotorShield();
Adafruit_DCMotor *pumpOne = MotorShield.getMotor(1);
Adafruit_DCMotor *pumpTwo = MotorShield.getMotor(2);
Adafruit_DCMotor *pumpThree = MotorShield.getMotor(3);
Adafruit_DCMotor *pumpFour = MotorShield.getMotor(4);



//  STIRRING CONTROLLER STUFF
const int motorStirringPinInputOne = 48;
const int motorStirringPinInputTwo = 46;



// HEATER CONTROLLER STUFF
const int heaterPlateTopPinEnable = 44;       // Top Heater Plate PWM Pin
const int heaterPlateTopPinInputOne = 42;
const int heaterPlateTopPinInputTwo = 40;
const int heaterPlateBottomPinEnable = 34;    // Bottom Heater Plate PWM Pin
const int heaterPlateBottomPinInputOne = 38;
const int heaterPlateBottomPinInputTwo = 36;



// THERMOMETER STUFF
//makes a null object of a thermistor to pass original thermistor into smoothing function
Thermistor* mediaTempThermistorSmooth = NULL;
Thermistor* heaterPlateTempThermistorSmooth = NULL;
const int thermistorMediaPin = A8;                    //arduino analog pin 8 for media thermistor data line
const int thermistorHeaterPlatePin = A9;              //arduino analog pin 9 for media thermistor data line
const int thermistorReferenceResistance = 10000;      //resistance value of Vishay PTF5610K000BZEK precision resistor
const int thermistorNominalResistance = 10000;        //rated thermistor resistance
const int thermistorNominalTemp = 25;                 //temp curves were calibrated for at thermistor factory
const int thermistorBValue = 3380;                    //taken from Murata NXFT15XH103FA1B150 NTC thermistor datasheet
const int thermistorSmoothingFactor = 5;              //how many samples to take and average



// PID STUFF
const double setpointOffset = 0.25; //added an extra 0.25 so average is more centered around 30C since gap trigger is setPointTemp - 0.5
double outputPWM = 0.00;
const double aggKp = 4, aggKi = 0.2, aggKd = 1;        //Define the aggressive and conservative Tuning Parameters
const double consKp = 1, consKi = 0.05, consKd = 0.25;
const double gapThreshold = 0.5;
//************SAFETY VARIABLE********************
const float pwmSafetyLimit = 130.00;    //DO **NOT** LET HEATER EXCEED GLASS TRANSITION POINT OF PRINTED MATERIAL (~106C)!!!
//************************************************/
PID mediaTempPID(&mediaTemp, &outputPWM, &currentMediaTempSetpoint, consKp, consKi, consKd, DIRECT);   //Specify the links and initial tuning parameters



// BUTTON STUFF
const int btnPinUp = 26;
const int btnPinSelect = 24;
const int btnPinDown = 22;
Switch BtnUp = Switch(btnPinUp);    //debounced switch objects
Switch BtnSelect = Switch(btnPinSelect);
Switch BtnDown = Switch(btnPinDown);



// LIGHT SENSOR STUFF
Adafruit_TSL2591 tsl = Adafruit_TSL2591(2591);
uint32_t lum;
uint16_t ir, full;
unsigned long IR;
unsigned long IRtotal;
float IRavg;
unsigned long IRblank;
unsigned long VIS;
unsigned long FULL;



// LED DRIVER STUFF
const int ledDriverPinData = 25;
const int ledDriverPinClock = 27;
const int ledDriverPinLatch = 23;
const int ledDriverPinEnable = -1;  //set to -1 to not use enable pin (optional)
Adafruit_TLC5947 ledDriver = Adafruit_TLC5947(1, ledDriverPinClock, ledDriverPinData, ledDriverPinLatch);
   
const int totalStimulationLEDCount = 6; //adjust according to how many stimulation LEDs you have; for-looped during standby state

// REAL-TIME CLOCK STUFF
RTC_DS3231 rtc;                           // defines real-time clock object
unsigned long previousMillis = 0;



// SD CARD STUFF
const int sdCardCSPin = 53;
File csvFile;
File configFile;
File cycleProgramFile;


// LCD SCREEN STUFF
LiquidCrystal_I2C lcd(0x27, 20, 4);     // set I2C address to 0x27 and a 20 chars x 4 line screen



StateMachine machine = StateMachine();
State* stateMenu = machine.addState(&stateFunctionMenu);
State* stateStandby = machine.addState(&stateFunctionStandby);
State* stateTurbidostat = machine.addState(&stateFunctionTurbidostat);
State* stateIncubate = machine.addState(&stateFunctionIncubate);
State* statePrimePumps = machine.addState(&stateFunctionPrimePumps);
State* stateHeaterTest = machine.addState(&stateFunctionHeaterTest);
State* stateCalibrateStirring = machine.addState(&stateFunctionCalibrateStirring);
State* stateCalibrateOptics = machine.addState(&stateFunctionCalibrateOptics);
State* stateCalibratePumpOne = machine.addState(&stateFunctionCalibratePumpOne);
State* stateCalibratePumpTwo = machine.addState(&stateFunctionCalibratePumpTwo);
State* stateCalibratePumpThree = machine.addState(&stateFunctionCalibratePumpThree);
State* stateCalibratePumpFour = machine.addState(&stateFunctionCalibratePumpFour);




//MENU STUFF
const String MenuItems[] =
{
  "TURBIDOSTAT",
  "INCUBATE",
  "PRIME PUMPS",
  "HEATER TEST",
  "CALIBRATE STIRRING",
  "CALIBRATE OPTICS",
  "CALIBRATE PUMP 1",
  "CALIBRATE PUMP 2",
  "CALIBRATE PUMP 3",
  "CALIBRATE PUMP 4"
};



// Select I2C BUS
void setMultiplexerFocus(uint8_t bus)
{
  Wire.beginTransmission(0x70);  // setMultiplexerFocus address
  Wire.write(1 << bus);          // send byte to select bus
  Wire.endTransmission();
}
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
void loop()
{
  //poll each of the buttons for any user input
  BtnUp.poll();
  BtnSelect.poll();
  BtnDown.poll();

  //activate the statemachine
  machine.run();
}



//=======================================
void stateFunctionMenu()
{
  setMultiplexerFocus(0);
  lcd.setCursor(0, 0);
  lcd.print("EasyEVO Type D");
  lcd.setCursor(0, 1);
  lcd.print(">");
  lcd.setCursor(1, 1);
  lcd.print(MenuItems [currentMenuItem]);

  if (BtnSelect.singleClick() == HIGH && button_flag == 0)
  {
    menuFunctions(currentMenuItem + 1, 1, 0);
    button_flag = 1;
    previousMillis = millis();
  }

  if (BtnSelect.longPress() == HIGH && button_flag == 0)
  {
    menuFunctions(currentMenuItem + 1, 0, 1);
    button_flag = 1;
    previousMillis = millis();
  }

  if (BtnDown.singleClick() == HIGH && button_flag == 0)
  {
    ++currentMenuItem;
    if (currentMenuItem > numberOfMenuItems )
    {
      currentMenuItem = numberOfMenuItems ;
    }
    button_flag = 1;
    previousMillis = millis();
  }

  else if (BtnUp.singleClick() == HIGH && button_flag == 0)
  {
    currentMenuItem--;
    if (currentMenuItem < 0)
    {
      currentMenuItem = 0;
    }
    button_flag = 1;
    previousMillis = millis();
  }

  if (currentMenuItem != previousMenuItem)
  {
    setMultiplexerFocus(0);
    lcd.clear();
    lcd.setCursor(0, 0);
    lcd.print("Main Menu 1/6");
    lcd.setCursor(0, 1);
    lcd.print(">");
    lcd.setCursor(1, 1);
    lcd.print(MenuItems [currentMenuItem]);
    menuFunctions(currentMenuItem + 1, 0, 0);
    previousMenuItem = currentMenuItem;
  }

  if (millis() - previousMillis >= 50)
  {
    previousMillis = millis();
    button_flag = 0;
  }
}


// the main active state of the easyEVO in TURBIDOSTAT mode. This records OD940 values and checks if the OD hit a user defined ceiling
void stateFunctionStandby()
{
  setMultiplexerFocus(0);
  stirringON();

 
  unsigned long currentMillis = millis();

  //ensure the bracketed function calls happen only once per user defined interval (usually one second)
  if (currentMillis - previousMillis >= interval)
  {
    previousMillis = currentMillis;

    
    //Serial.print("Stdby Pump Number: ");
    //Serial.println(currentMediaPumpNumber);

    //calculate the heater plate's current temperature and the PID controller's output to maintain user defined media temp
    heaterCompute(currentMediaTempSetpoint);

    //reset the transition flag to keep the easyEVO in standby mode until optical density trigger occurs
    flagGoToTurbidostat = false;

    //measure the optical density of the reaction tube
    calculateOD940();

    //check if optical density hit ceiling threshold, if so then transition into the turbidostat state function to dispense media
    if (currentOD940 >= currentOpticalDensityCeiling)
    {
      flagGoToTurbidostat = true;
    }

      ledDriver.setPWM(currentStimulationLEDNumber, currentStimulationLEDIntensity); 
      ledDriver.write();

    //display relevant information on the LCD screen, oscillating between two pages
    if (displayStatPage == true)
    {
       displayStats();
       displayStatPage = false;
    }
    else
    {
      displaySecondaryStats();
      displayStatPage = true;
    }
   

    //save light values
    writeToCard();
  }
}

//conditional which if true, executes a transition for standby mode to the main menu
bool transitionStandbyToMenu()
{
  if (BtnSelect.longPress() == HIGH)
  {
    //set I2C focus back to LCD screen and turn off all the motors, heater, and pumps
    setMultiplexerFocus(0);
    stirringOFF();
    heaterOFF();
    allPumpsStop();
    //set all stimulation LED lights to zero, save for the OD940 LED at position zero
    resetStimulationLights();
    currentCycleStep = 1;   //comment out to resume from last step instead of rebooting the cycler upon escape to menu
    growthStartTime = 0;
    growthStopTime = 0;
    programStartTime = 0;
    flagGoToStandby = false;
    lcd.clear();
    return true;
  }

  return false;
}



//TURBIDOSTAT STATE
void stateFunctionTurbidostat()
{
  setMultiplexerFocus(0);
  stirringON();
    
  unsigned long currentMillis = millis();

  if (currentMillis - previousMillis >= intervalTurbidostat)
  {
    previousMillis = currentMillis;
    heaterCompute(currentMediaTempSetpoint);

    //Serial.print("Pump Number: ");
    //Serial.println(currentMediaPumpNumber);
    dispenseMedia(currentMediaPumpNumber); 

    currentMediaDispenseCount++;
    float totalOD940 = 0.00;
    float averageOD940 = 0.00;
    for (int i = 0; i <= 9; i++)
    {
      calculateOD940();
      totalOD940 = totalOD940 + currentOD940;
    }

    averageOD940 = totalOD940 / 10;
    currentOD940 = averageOD940;      //THIS IS FOR A TSL2591 LIGHT SENSOR INTEGRATION TIME OF 100ms ONLY!

    removeMedia(wastePumpNumber); //typically pump 4 is dedicated waste line  

    totalOD940 = 0.00;
    averageOD940 = 0.00;
    for (int i = 0; i <= 9; i++)
    {
      calculateOD940();
      totalOD940 = totalOD940 + currentOD940;
    }

    averageOD940 = totalOD940 / 10;
    currentOD940 = averageOD940;      //THIS IS FOR A TSL2591 LIGHT SENSOR INTEGRATION TIME OF 100ms ONLY!

    //dilute to the next step's optical density floor value to allow full growth starting from desired density of next cycle
    int nextCycleStep = currentCycleStep + 1;
    currentOpticalDensityFloor = mediaCycleArray[nextCycleStep][5].toFloat();
    
    if (currentCycleStep == totalProgramCycles - 1)
    {
      //if current step is last step in cycle, set the optical density floor to the first step's value
      currentOpticalDensityFloor = mediaCycleArray[1][5].toFloat();
    }

    if (currentOD940 <= currentOpticalDensityFloor)
    {
      allPumpsStop();
      flagGoToStandby = true;
    }
    displayStats();
    writeToCard();
  }
}

bool transitionTurbidostatToMenu()
{
  if (BtnSelect.longPress() == HIGH)
  {
    setMultiplexerFocus(0);
    stirringOFF();
    heaterOFF();
    allPumpsStop();
    //set all stimulation LED lights to zero, save for the OD940 LED at position zero
    resetStimulationLights();
    currentCycleStep = 1; //reset the current step count when exiting to menu
    growthStartTime = 0;
    growthStopTime = 0;
    programStartTime = 0;
    lcd.clear();
    return true;
  }

  return false;
}

bool transitionTurbidostatToStandby()
{
  if (flagGoToStandby == true)
  {
    setMultiplexerFocus(1);

    DateTime now = rtc.now();

    totalCycleCount++;
    currentCycleStep++;

    
  if (currentCycleStep >= totalProgramCycles)
    {
      currentCycleStep = 1; //reset the current step count to loop the cycler program forever
    }

      currentStepNumber = mediaCycleArray[currentCycleStep][0].toInt();
      currentMediaType = mediaCycleArray[currentCycleStep][1];      //"NEUTRAL", "POSITIVE", or "NEGATIVE" (media pumps 1, 2, and 3 respectively)
      currentMediaTempSetpoint = mediaCycleArray[currentCycleStep][2].toDouble();
      currentStimulationLEDNumber = mediaCycleArray[currentCycleStep][3].toInt();
      currentStimulationLEDIntensity = mediaCycleArray[currentCycleStep][4].toInt();
      currentOpticalDensityFloor = mediaCycleArray[currentCycleStep][5].toFloat();
      currentOpticalDensityCeiling = mediaCycleArray[currentCycleStep][6].toFloat();
      currentStirringSpeed = mediaCycleArray[currentCycleStep][7].toInt();
      currentCycleTimeoutDuration = mediaCycleArray[currentCycleStep][8].toInt();
   

    if (currentMediaType == "NEUTRAL")
    {
      currentMediaPumpNumber = 1;
    }
    
    if (currentMediaType == "POSITIVE")
    {
      currentMediaPumpNumber = 2;
    }
    
    if (currentMediaType == "NEGATIVE")
    {
      currentMediaPumpNumber = 3;
    }

    growthStartTime = now.unixtime() - programStartTime;  //start timing new growth cycle

    //set I2C multiplexer to I2C channel zero (LCD screen);
    setMultiplexerFocus(0); 

    //shut off all the pumps, for safety
    allPumpsStop();

    //set all stimulation LED lights to zero, save for the OD940 LED at position zero
    resetStimulationLights();

    //reset the flag that triggers transition between standby and turbidostat states                                                           
    flagGoToTurbidostat = false;                                              
    return true;
  }

  return false;
}
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

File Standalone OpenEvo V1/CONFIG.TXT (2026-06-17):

incubationSetpointTemp=30.00
OD940LEDBrightness=2460
motorStirringSpeed=84
pumpOneSpeed=1161
pumpTwoSpeed=1140
pumpThreeSpeed=1140
pumpFourSpeed=1160
END

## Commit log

2023-04-18 First upload of all critical files
    [Bill of Materials.xlsx, FauxVOLVER Blank Module.stl, FauxVOLVER LCD Faceplate.stl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]
2023-06-06 added new switch handling library
2023-06-07 removed old STL Files
    [FauxVOLVER Blank Module.stl, FauxVOLVER LCD Faceplate.stl, FauxVOLVER LCD Rail.stl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]
2023-06-07 updated latest STL files for Type S
    [Blank Module.stl, Bottle Cap Mold Cover.stl, LCD Faceplate.stl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]
2026-06-11 added new BOM and Wiring List
    [Older Bill of Materials.xlsx, Wiring Checklist.xlsx]
2026-06-11 Updating STL Files
    [Blank Module.stl, Bottle Cap Mold Cover.stl, LCD Faceplate.stl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]
2026-06-11 Added Build Info Files
    [Older Bill of Materials.xlsx, Wiring Checklist.xlsx]
2026-06-17 Added software, firmware and STL files, etc
    Added software, firmware and STL files, etc
    [2026 Updated Bill of Materials.xlsx, CONFIG.TXT, Module A - OEVO LCD Rail.stl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]
2026-06-17 Compressed assembly manual to fit on Github, reorganized files and readme files accordingly
    Compressed assembly manual to fit on Github, reorganized files and readme files accordingly
    [2026 Updated Bill of Materials.xlsx, CONFIG.TXT, Module A - OEVO LCD Rail.stl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]
2026-06-17 Create easyEVO LED Characterization.xlsx
    added LED data
    [easyEVO LED Characterization.xlsx]
2026-06-17 renamed file
    [OpenEVO LED Characterization.xlsx]
2026-06-17 added wiring checklist and Standalone manual
    [Wiring Checklist.xlsx]
